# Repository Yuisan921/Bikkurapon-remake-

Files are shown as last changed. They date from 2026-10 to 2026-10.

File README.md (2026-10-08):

# びっくらポン（文化祭リメイク版）

回転寿司でおなじみの「びっくらポン」を、文化祭のミニゲームとして再現するプロジェクトです。

コインを入れる  
→ 画面で抽選演出  
→ 抽選結果を決定  
→ 当たり用 / はずれ用それぞれのホッパーからサーボモーターでカプセルを排出  
→ 結果を画面に表示

という一連の流れを実装しています。

**どちらの結果でも必ずカプセルが1個出ます。**

- 当たり → 当たり用ホッパーから景品カプセルを排出
- はずれ → はずれ用ホッパーから参加賞カプセルを排出

という2ホッパー構成です。

---

# クイックスタート（まずはこれだけ）

## PC側について

このプロジェクトの `.exe` は、一般的な単体アプリとは少し仕組みが異なります。

**パソコンの中で小さなWebサーバーを起動し、その画面をブラウザで表示する方式です。**

ブラウザだけでは、USB接続されたArduinoやコインセンサー、サーボモーターと直接通信できないため、必ず `.exe` を起動した状態で使用します。

逆に言えば、`.exe` が起動していれば、

- ゲーム演出
- 抽選
- 在庫管理
- Arduinoとの通信
- 管理画面

などはすべて自動的に動作します。

## 起動手順

1. `BikkurapoSetup.exe` をインストールする  
   入手方法は後述の「インストーラーを使う」を参照してください。

2. スタートメニューまたはデスクトップの「びっくらポン」を起動する

3. 裏側でサーバーが起動し、自動で次の2つのウィンドウが開きます。

   - **演出画面**
   - **管理画面**

4. 普段のテストでは通常のウィンドウ表示になります。

   文化祭当日に外部モニターへフルスクリーン表示したい場合は、`config/settings.json` の `kiosk_mode` を `true` にしてください。

5. 演出画面右下にある「コインを投入（テスト用）」ボタンを押すと、Arduinoを接続していなくても抽選演出から結果表示まで確認できます。

6. Arduino UNOまたはUNO互換ボードをUSBでノートPCに接続すると、実際のコインセンサーからゲームを開始できるようになります。

   通常はシリアルポートを自動検出します。

   うまく認識されない場合は、`config/settings.json` の `serial_port` に、

   ```json
   "serial_port": "COM3"
``

のようにCOMポートを手動指定してください。

7.  景品、確率、在庫などを変更する場合は `config/prizes.json` を編集します。

## 困ったとき

次の順番で確認すると原因を切り分けやすくなります。

1.  演出画面右下のテストボタンでソフト単体が動くか
2.  `/admin` で在庫が正常に表示されるか
3.  ArduinoがWindowsでCOMポートとして認識されているか
4.  Arduino IDEのシリアルモニターでコイン投入が検知されているか
5.  サーボがArduino単体で正常に動くか

----------

# 全体構成（役割分担）

本体は主に次の2つの機器で構成されています。

## ノートPC

抽選ロジックと画面表示を担当します。

主な役割は次の通りです。

-   抽選処理
-   景品在庫管理
-   演出画面表示
-   管理画面表示
-   ArduinoとのUSBシリアル通信
-   排出予約
-   排出完了確認
-   データ保存

PC側からGPIOなどを直接操作することはありません。

## Arduino UNO / UNO互換ボード

ハードウェア制御を担当します。

主な役割は次の通りです。

-   コインセンサー入力
-   コイン投入検知
-   当たり用サーボ制御
-   はずれ用サーボ制御
-   ノートPCとのUSBシリアル通信
-   カプセル排出完了通知

文化祭本番では、

**Arduino UNO / UNO互換ボード + USB接続**

を標準構成として使用します。

----------

# 使用できるマイコン

このプロジェクトでは複数の接続方法を用意しています。

接続方法

マイコン

ファームウェア

用途

USB（推奨）

Arduino UNO / UNO互換

`firmware/arduino_uno_usb_serial/`

文化祭本番向け。学校にあるUNOを使用可能

USB

Seeed XIAO ESP32-C3

`firmware/xiao_esp32c3_usb_serial/`

小型化したい場合

Wi-Fi

Seeed XIAO ESP32-C3

`firmware/xiao_esp32c3_wifi_http/`

PCとマイコンを離して設置したい場合

文化祭ではWi-Fi環境に左右されず、USBケーブルのみで通信できるArduino UNO版を推奨します。

画面表示に必要なJavaScriptライブラリなどもアプリに同梱しているため、USB版はインターネット接続なしでも動作します。

----------

# 通信の流れ（USB版）

Arduino UNO版とXIAO USB版では、PCとの通信方式を共通化します。

## 1. コイン投入

Arduinoがコインセンサーの投入を検知します。

ArduinoからPCへ、

```
COIN:<番号>
```

を送信します。

例：

```
COIN:1
```

----------

## 2. PC側で抽選

PC側で景品を抽選します。

この時点では、まだ在庫は確定して減らしません。

排出対象がある場合、PCからArduinoへ、

```
DISPENSE:<coinId>:<reservationId>:<hopper>
```

を送信します。

例：

```
DISPENSE:1:abc123:A
```

`hopper` は、

-   `A` → 当たり用ホッパー
-   `B` → はずれ用ホッパー

を表します。

----------

## 3. Arduinoがカプセルを排出

Arduinoは指定されたホッパーのサーボモーターを動かします。

実際にカプセルを排出します。

----------

## 4. 排出完了通知

サーボ動作が完了したら、ArduinoからPCへ、

```
DONE:<reservationId>
```

を返します。

例：

```
DONE:abc123
```

----------

## 5. 在庫確定

PCは `DONE` を受信して初めて在庫を1個減らします。

その後、ゲーム画面へ抽選結果を通知します。

この方式により、

-   USBケーブルが途中で抜けた
-   Arduinoが応答しなかった
-   サーボ排出処理が開始できなかった
-   通信がタイムアウトした

といった場合に、実際には景品が出ていないのに在庫だけ減る事故を防ぎます。

失敗した予約はキャンセルされます。

----------

# Wi-Fi版について

XIAO ESP32-C3を使用する場合はWi-Fi版も利用できます。

Wi-Fi版でも考え方はUSB版と同じです。

カプセル排出後に完了ACKをPCへ送信してから、在庫を確定します。

詳細は、

```
firmware/xiao_esp32c3_wifi_http/xiao_esp32c3_wifi_http.ino
```

のコメントを参照してください。

----------

# カプセル排出機構（CAD）

`cad/capsule_dispenser.scad` に、縦置き中空ドラム式のパラメトリックモデルがあります。

OpenSCADで編集できます。

完成したドラム外観：

![中空ドラムローター外観](cad/capsule_dispenser_drum.png)

前面板を外した内部確認表示：

![中空ドラムローター内部](cad/capsule_dispenser_cutaway.png)

NEMA17用の中央穴と31mm角固定穴：

![ステッピングモーター取付穴](cad/capsule_dispenser_stepper_mount.png)

## 基本構造

画像で検討した円筒をタイヤのように縦置きし、中央のステッピングモーターの水平軸で回転させます。

中空ドラムの外周には180度対向の窓が2個あり、内部は中央仕切りと左右ガイドで1カプセル幅の上下2室に分かれています。

1.  上側のポケットへカプセルが1個入る
2.  ローターを180度回転させる
3.  カプセルが下側へ移動する
4.  排出口からカプセルが落ちる
5.  同時に反対側の空ポケットが上へ移動する
6.  次のカプセルが装填される

という構造です。

ローター回転中はケースの円形内壁がドラム窓を塞ぐため、後続のカプセルが一緒に落ちにくい構造になっています。

ドラムは印刷時の大きなブリッジを避けるため、前面・外周・内部仕切りが一体の `rotor_body` と、後面支持軸付きの `rotor_lid` に分かれています。

当たり用・はずれ用で同じ排出機構を2セット使用します。

## カプセルサイズ

既定値は、一般的な大型カプセルを想定した、

```
capsule_diameter = 65mm
```

です。

実際に使用するカプセルをノギスなどで測定し、必要に応じて変更してください。

例えば、

-   45mm
-   48mm
-   50mm
-   65mm

などに対応できます。

## STL出力

OpenSCADでファイルを開き、冒頭の `PART` を切り替えます。

主なパーツは、

```
"rotor_body"
"rotor_lid"
"housing"
"front_plate"
"rear_plate"
"hopper_adapter"
"outlet_adapter"
```

です。

それぞれ個別にSTLへ出力します。

```
"assembly"
"assembly_cutaway"
```

は組み立て確認用です。`assembly_cutaway` では前面を外し、内部仕切りとカプセル位置を確認できます。

STL出力用ではありません。

`ROTOR_PREVIEW_ANGLE` を、

```
0
```

または、

```
180
```

へ変更すると、ローターの2つの停止位置を確認できます。

## 3Dプリンタサイズ

65mmカプセル設定の場合、ドラムは外径146mm、ケース・前後プレート外形は約156×156mmです。

一般的な、

```
160mm × 160mm
```

の造形範囲へ収まる設計です。ただし、スカートやブリムを付けると160mmを超える場合があるため、スライサー上でも最終確認してください。

## 組み立て

1セットにつき、

-   ローター本体（`rotor_body`）
-   ローター後ろ蓋（`rotor_lid`）
-   ケース
-   フロントプレート
-   リアプレート
-   ホッパーアダプター
-   排出口アダプター

を印刷します。

ローター本体と後ろ蓋はM3低頭ねじ4本で固定します。後ろ蓋には、ねじ頭がケースへ擦らないよう座ぐりがあります。

前後プレートとケースはM4通しボルト4本で固定します。

前面プレート中央には、初期値としてNEMA17用の22.5mm中央穴と31mm角のM3固定穴4個があります。

ローター前面には5.4mmの軸穴と、5mmシャフト用フランジハブを固定する4穴があります。ハブ穴ピッチは製品差があるため、`rotor_hub_*` パラメータを実物へ合わせてください。

ローター後面の軸は `rear_plate` で支持します。

モーターの寸法がNEMA17と異なる場合は、

```
stepper_*
rotor_hub_*
```

系パラメータを実物に合わせて調整してください。

----------

# ステッピングモーターの動作方式

現在の180度ローター構造では、

```
0度
↓
180度
↓
0度
↓
180度
...
```

のように、排出するたびに2つの停止位置を交互に使用する方式が適しています。

排出後に毎回元の位置へ戻さないことで、ローターの1回転分の移動を減らし、排出時間を短縮できます。

ステッピングモーターでは、使用するモーターの1回転ステップ数とマイクロステップ設定から半回転分のパルス数を決めます。原点ずれを確実に防ぐ場合は、別途ホームセンサーの追加を推奨します。

**注意：現在のマイコンファームウェアはサーボ制御のままです。CADの中央ステッピングモーター化に合わせて、STEP/DIRドライバー制御へ変更する必要があります。**

----------

# ホッパー

背の高いカプセル貯留部分は3Dプリントしません。

代わりに、

-   透明アクリルパイプ
-   PET素材の筒
-   透明容器
-   自作ホッパー

などを `hopper_adapter` へ接続します。

65mmカプセルの既定設定では、通路内径は約68.5mmです。

カプセルが単列で流れるようにしてください。

途中で2個が横並びになる構造にすると、詰まりやすくなります。

また、入口直前へ大量のカプセル重量が集中するとローターへ強い力が掛かり、噛み込みが起きる可能性があります。

必要に応じて傾斜板などを設け、ローターへ直接大きな荷重が掛からない構造にしてください。

----------

# ステッピングモーター

CADの初期値は、中央取付の、

**5mm軸NEMA17ステッピングモーター**

へ合わせています。必要トルクはカプセル重量、ホッパー荷重、ドラムの摩擦によって変わるため、実機で余裕を確認してください。

必要数は、

```
2個
```

です。

-   当たり用 ×1
-   はずれ用 ×1

----------

# ステッピングモータードライバーと電源について

ステッピングモーターはArduinoやXIAOの端子へ直接接続できません。モーターごとにA4988やTMC2209などのSTEP/DIR対応ドライバーと、モーター仕様に合う外部電源が必要です。

**モーター電源をマイコンの5V端子から供給しないでください。**

基本構成は、

-   マイコンからドライバーへSTEP/DIR信号
-   外部電源からドライバーへモーター電源
-   マイコンとドライバーのGNDを共通化
-   ドライバーの電流制限を使用モーターへ合わせて調整

です。

使用するドライバーと電源電圧がまだ確定していないため、STEP/DIRのピン番号と配線図はファームウェア変更時に確定します。README後半のサーボ配線・サーボ用ファームウェア説明は現行実装の記録であり、ステッピングモーター版へ更新が必要です。

----------

# リポジトリの構成

```
Bikkurapon-remake-/
│
├─ run.py
│
├─ app/
│  ├─ server.py
│  ├─ lottery.py
│  ├─ serial_bridge.py
│  ├─ paths.py
│  ├─ browser_launcher.py
│  └─ config_setup.py
│
├─ config/
│  ├─ prizes.json
│  └─ settings.json
│
├─ data/
│  └─ stock.json
│
├─ firmware/
│  ├─ arduino_uno_usb_serial/
│  │  └─ arduino_uno_usb_serial.ino
│  │
│  ├─ xiao_esp32c3_usb_serial/
│  │  └─ xiao_esp32c3_usb_serial.ino
│  │
│  └─ xiao_esp32c3_wifi_http/
│     └─ xiao_esp32c3_wifi_http.ino
│
├─ cad/
│  └─ capsule_dispenser.scad
│
├─ templates/
│
├─ static/
│
├─ scripts/
│
├─ installer/
│
├─ tests/
│
├─ bikkurapon.spec
├─ requirements.txt
├─ requirements-dev.txt
├─ requirements-build.txt
└─ README.md
```

## 主なファイル

### `run.py`

アプリの起動エントリーポイントです。

### `app/server.py`

Flask + Socket.IOによるサーバー本体です。

ノートPC上で動作します。

### `app/lottery.py`

-   確率抽選
-   景品選択
-   在庫管理
-   排出予約

などを担当します。

### `app/serial_bridge.py`

Arduino UNOまたはXIAO ESP32-C3とのUSBシリアル通信を担当します。

-   コイン投入受信
-   排出命令送信
-   DONE応答受信
-   再接続処理

などを行います。

### `app/paths.py`

通常のPython実行とPyInstallerによる `.exe` 実行時のパス解決を切り替えます。

### `app/browser_launcher.py`

起動時に、

-   演出画面
-   管理画面

を自動的にブラウザで開きます。

### `bikkurapon.spec`

PyInstallerで `.exe` を作成するための設定です。

### `installer/bikkurapon.iss`

Inno SetupでWindowsインストーラーを作るための設定です。

### `.github/workflows/build-windows.yml`

GitHub Actions上のWindows環境で、

-   テスト
-   `.exe` 作成
-   インストーラー作成

を自動実行します。

### `config/prizes.json`

次の内容を設定します。

-   景品
-   当選確率
-   初期在庫
-   使用するホッパー

### `config/settings.json`

次のような設定を行います。

-   HTTPポート
-   USBシリアルポート
-   ブラウザ自動起動
-   キオスクモード
-   外部アクセス許可
-   デバッグボタン表示

### `templates/`, `static/`

-   演出画面 `/`
-   在庫管理画面 `/admin`

に使用するHTML、CSS、JavaScriptなどです。

### `data/stock.json`

現在の在庫数を保存します。

実行時に自動生成されます。

Git管理対象外です。

### `firmware/arduino_uno_usb_serial/`

Arduino UNO / UNO互換ボード用のUSBシリアル版ファームウェアです。

**文化祭本番での推奨構成です。**

### `firmware/xiao_esp32c3_usb_serial/`

Seeed XIAO ESP32-C3用USBシリアル版です。

### `firmware/xiao_esp32c3_wifi_http/`

Seeed XIAO ESP32-C3用Wi-Fi版です。

### `cad/capsule_dispenser.scad`

カプセル排出機構のパラメトリックCADです。

### `scripts/`

開発用の起動スクリプトや `.exe` ビルドスクリプトなどが入っています。

----------

# 必要なハードウェア

## 推奨構成

-   WindowsノートPC
-   Arduino UNO または UNO互換ボード
-   USB Type-Bケーブル
-   コインセンサー
-   高トルク180度サーボ ×2
-   サーボ用外部5〜6V電源
-   ブレッドボードまたは配線基板
-   ジャンパーワイヤ
-   カプセル排出機構 ×2
-   カプセル
-   外部モニター（任意）

## 推奨サーボ

MG996R相当の、

-   金属ギア
-   高トルク
-   180度動作

のサーボを推奨します。

----------

# Arduino UNO配線

## 基本配線

部品

Arduino UNO

コインセンサー信号

D2

当たり用ホッパー サーボ信号

D9

はずれ用ホッパー サーボ信号

D10

GND

GND

D0とD1はUSBシリアル通信で使用されるため、通常は使いません。

## コインセンサー

コインセンサーは、

**投入時にLOWになる構成**

を想定しています。

Arduino側では、

```
pinMode(COIN_SENSOR_PIN, INPUT_PULLUP);
```

を使用します。

そのためテスト時には普通のスイッチでも代用できます。

```
Arduino D2
   │
   └── スイッチ ── GND
```

スイッチを押すとLOWになり、コイン投入として扱われます。

----------

# セットアップ

# ノートPC側 その1：インストーラーを使う（推奨）

Windowsのユーザー名に、

-   日本語
-   ひらがな
-   カタカナ
-   その他の非ASCII文字

などが含まれている場合、Python仮想環境やバッチファイル周辺で文字コード関連の問題が起きることがあります。

そのため、このプロジェクトではGitHub Actions上のWindows環境で `.exe` とインストーラーを自動生成できるようにしています。

## 入手方法

1.  GitHubリポジトリの `Actions` タブを開く
    
2.  `build-windows.yml` の最新ビルドを開く
    
3.  Artifacts欄から、
    
    ```
    BikkurapoSetup
    ```
    
    をダウンロードする
    
4.  ZIPを展開する
    
5.  中にある、
    
    ```
    BikkurapoSetup.exe
    ```
    
    を実行する

ビルドがまだ存在しない場合や最新化したい場合は、GitHub Actionsから、

```
Run workflow
```

を実行してください。

----------

# インストール・実行

`BikkurapoSetup.exe` を起動してインストールすると、

-   スタートメニュー
-   デスクトップ

に「びっくらポン」のショートカットが作成されます。

ショートカットをダブルクリックすると、

1.  Webサーバー起動
2.  Arduino接続待機
3.  演出画面起動
4.  管理画面起動

まで自動的に行われます。

バッチファイルを手動で実行する必要はありません。

----------

# 設定ファイルの保存場所

設定フォルダの場所は、実行ファイルの場所へ書き込み可能かどうかによって変わります。

例えば、

```
C:\Program Files\
```

のような一般ユーザーが書き込めない場所へインストールした場合は、

```
%LOCALAPPDATA%\Bikkurapon\config\
```

へ設定ファイルが作成されます。

在庫データも、

```
%LOCALAPPDATA%\Bikkurapon\data\
```

側へ保存されます。

現在使用している設定フォルダは、起動時のコンソールにも、

```
設定フォルダ: ...
```

として表示されます。

----------

# アンインストール

Inno Setup製インストーラーにはアンインストーラーが自動的に付属します。

削除する場合は、次のどちらかを使用できます。

## 方法1

スタートメニューの「びっくらポン」フォルダ内にある、

```
Uninstall びっくらポン
```

を実行します。

## 方法2

Windowsの、

```
設定
→ アプリ
→ インストールされているアプリ
```

から「びっくらポン」を探してアンインストールします。

新しいバージョンへ更新する場合は、基本的に上書きインストール可能です。

必ずアンインストールする必要はありません。

----------

# ノートPC側 その2：.exeを自分でビルドする

インストーラーを使わず、自分で `.exe` を作成することもできます。

Windowsの場合、

```
scripts\build_exe.bat
```

を実行します。

成功すると、

```
dist\bikkurapon.exe
```

が生成されます。

ダブルクリックすると、

-   サーバー
-   演出画面
-   管理画面

が起動します。

初回起動時には必要に応じて、

```
config\
data\
```

が自動作成されます。

以降、景品や確率を変更するだけなら `.exe` を作り直す必要はありません。

## 注意

PyInstallerで生成される実行ファイルは、

**ビルドしたOS向けの実行ファイルです。**

Windowsでビルドした場合はWindows用になります。

----------

# ノートPC側 その3：Pythonで直接動かす（開発用）

Python環境から直接実行する場合は、仮想環境を作成します。

Mac / Linux：

```
python3 -m venv venv
source venv/bin/activate
pip install -r requirements.txt
python run.py
```

Windows：

```
python -m venv venv
venv\Scripts\activate
pip install -r requirements.txt
python run.py
```

Arduinoが接続されていなくてもアプリ自体は起動できます。

バックグラウンドでUSBシリアル接続を待ち続けます。

後からArduinoを接続して、

```
USBシリアルに再接続しました
```

と表示されれば接続成功です。

----------

# シリアルポートを手動設定する

自動検出できない場合は、

```
config/settings.json
```

の `serial_port` を指定します。

Windowsの例：

```
"serial_port": "COM3"
```

Linux系の例：

```
"serial_port": "/dev/ttyACM0"
```

ポート番号は環境によって変わります。

Arduino IDEの、

```
ツール
→ ポート
```

から確認できます。

----------

# 演出画面

アプリ起動後、

```
http://localhost:5000/
```

で演出画面へアクセスできます。

通常は自動的に開くため、手入力する必要はありません。

----------

# 管理画面

管理画面は、

```
http://localhost:5000/admin
```

です。

こちらも通常は自動的に開きます。

----------

# 演出画面・管理画面の自動起動

サーバーを起動すると、

```
app/browser_launcher.py
```

が、

-   演出画面
-   管理画面

を自動的に別ウィンドウで起動します。

通常はタイトルバー付きウィンドウとして開きます。

1台のモニターでテストするときは自由に移動できます。

----------

# ブラウザ自動起動を無効にする

`config/settings.json` の、

```
"auto_open_browser": false
```

を指定すると、自動起動を無効化できます。

その場合は手動で、

```
http://localhost:5000/
```

と、

```
http://localhost:5000/admin
```

を開いてください。

----------

# キオスクモード

文化祭本番で演出画面を外部モニターへフルスクリーン表示する場合は、

```
"kiosk_mode": true
```

を設定します。

演出画面がタイトルバーなしのフルスクリーン表示になります。

来場者が誤ってブラウザ操作したり、別ページへ移動したりすることを防ぎやすくなります。

普段の開発中は、

```
"kiosk_mode": false
```

を推奨します。

----------

# 外部モニター位置

演出画面を外部モニターの決まった位置へ表示したい場合は、

```
"kiosk_window_position": "1920,0"
```

のように指定できます。

数値はWindowsのディスプレイ配置によって異なります。

分からない場合は、

```
"kiosk_window_position": null
```

のままにして、手動でウィンドウを移動してください。

ChromeまたはChromiumが見つからない場合は、既定ブラウザで演出画面のみ開く場合があります。

その場合、管理画面は手動で `/admin` を開いてください。

----------

# 開発用起動スクリプト

開発用として、

```
scripts/start_bikkurapon.bat
```

および、

```
scripts/start_bikkurapon.sh
```

があります。

これらは環境構築とサーバー起動を補助するスクリプトです。

ブラウザ自体はサーバー側から起動します。

----------

# Arduino UNO側セットアップ

## 必要なもの

-   Arduino IDE
-   Arduino UNO / UNO互換ボード
-   USB Type-Bケーブル

Arduino UNOの場合、通常は追加ボードパッケージは必要ありません。

## ボード設定

Arduino IDEで、

```
ツール
→ ボード
→ Arduino AVR Boards
→ Arduino Uno
```

を選択します。

## ポート

ArduinoをUSB接続して、

```
ツール
→ ポート
```

からArduinoのCOMポートを選びます。

----------

# Arduino UNOファームウェア

次のファイルをArduino IDEで開きます。

```
firmware/arduino_uno_usb_serial/arduino_uno_usb_serial.ino
```

Arduino UNOへ書き込んでください。

----------

# Arduino UNOで使用するライブラリ

サーボ制御には、

```
#include <Servo.h>
```

を使用します。

Arduino標準のServoライブラリを使用するため、通常は別途ライブラリを追加する必要はありません。

----------

# Arduino UNOのピン

標準設定では、

```
const int COIN_SENSOR_PIN = 2;
const int SERVO_A_PIN = 9;
const int SERVO_B_PIN = 10;
```

とします。

つまり、

機能

ピン

コインセンサー

D2

当たりサーボ

D9

はずれサーボ

D10

です。

----------

# シリアル通信速度

PCとのUSBシリアル通信は、

```
115200 baud
```

を使用します。

Arduino IDEのシリアルモニターを開く場合も115200に設定してください。

----------

# Arduino単体でコイン検知を確認する

PCアプリを起動する前に、Arduino IDEのシリアルモニターで確認できます。

コインセンサーを反応させると、

```
COIN:1
```

次の投入では、

```
COIN:2
```

のように連番が表示されます。

----------

# XIAO ESP32-C3 USB版

Arduino UNOを使用しない場合は、既存のXIAO ESP32-C3 USB版も利用できます。

ファームウェア：

```
firmware/xiao_esp32c3_usb_serial/xiao_esp32c3_usb_serial.ino
```

Arduino IDEで、

```
XIAO_ESP32C3
```

を選択します。

さらに、

```
Tools
→ USB CDC On Boot
→ Enabled
```

へ設定してください。

USBシリアル通信に必要です。

## 必要ライブラリ

```
ESP32Servo
```

を使用します。

----------

# XIAO ESP32-C3 Wi-Fi版

Wi-Fi通信を使用する場合は、

```
firmware/xiao_esp32c3_wifi_http/
```

を使用します。

ファームウェア内の、

```
WIFI_SSID
WIFI_PASSWORD
SERVER_URL
DEVICE_TOKEN
```

を設定してください。

PC側の `config/settings.json` では、

```
"host": "0.0.0.0",
"allow_remote_insert_coin": true
```

などを設定する必要があります。

`device_token` は16文字以上の推測されにくい文字列を推奨します。

PC側とESP32側で同じ値を設定してください。

----------

# インターネットなしのルーター / APでWi-Fi版を使用する

Wi-Fi版はインターネット接続自体は必要ありません。

ノートPCとESP32が同じLAN内にいれば通信できます。

## 手順

1.  ルーターのDHCPを有効にする
    
2.  ノートPCとESP32を同じSSIDへ接続する
    
3.  ゲストWi-FiやAP分離機能は使用しない
    
4.  Windowsで、
    
    ```
    ipconfig
    ```
    
    を実行する
    
5.  ノートPCのIPv4アドレスを確認する
    
6.  ESP32の `SERVER_URL` を、
    
    ```
    http://<PCのIP>:5000/api/insert_coin
    ```
    
    に設定する
    
7.  PCの `settings.json` で、
    
    ```
    "host": "0.0.0.0",
    "allow_remote_insert_coin": true
    ```
    
    を有効にする
    
8.  Windowsファイアウォールの確認が表示されたら、プライベートネットワークを許可する

Socket.IOなど、画面表示に必要なライブラリも、

```
static/vendor/
```

から読み込むため、WAN側のインターネット接続は不要です。

USB版ではこの設定は必要ありません。

----------

# 景品・確率のカスタマイズ

景品設定は、

```
config/prizes.json
```

を編集します。

既定では、

-   当たり
-   はずれ

の2種類です。

例：

```
{
  "id": "atari",
  "name": "当たり",
  "probability": 0.2,
  "stock": 30,
  "hopper": "a"
}
```

## probability

当選確率です。

例：

```
"probability": 0.2
```

なら20%です。

各景品の確率合計が、

```
1.0
```

になるように設定してください。

----------

# stock

初期在庫数です。

例：

```
"stock": 30
```

なら30個です。

```
"stock": null
```

にすると在庫無制限として扱います。

----------

# hopper

使用する排出ホッパーです。

```
"hopper": "a"
```

→ 当たり用

```
"hopper": "b"
```

→ はずれ用

```
"hopper": null
```

→ カプセルを排出しない

という意味です。

----------

# 在庫切れになった景品

在庫が0になった景品は自動的に抽選対象から除外されます。

残っている景品だけを使用して再抽選されます。

----------

# 全景品の在庫がなくなった場合

全景品の在庫がなくなると、抽選はエラー扱いになります。

この場合、

-   カプセルを排出しない
-   在庫を減らさない
-   マイコンへ排出なしを通知
-   演出画面を在庫切れ表示へ変更

します。

演出画面には、

```
巫女さんを呼んでください
```

と表示されます。

管理画面から在庫を補充すると、自動的に通常の待機画面へ戻ります。

在庫切れ中にコインを投入した来場者への対応は、スタッフ側でメダル返却などを行う想定です。

`stock: null` の景品を1つ用意しておけば、全在庫切れ状態にはなりません。

----------

# 初期在庫を変更した場合

`config/prizes.json` の初期在庫を変更しても、既に、

```
data/stock.json
```

が存在する場合は現在在庫が優先されます。

初期在庫から作り直したい場合は、

```
data/stock.json
```

を削除してからアプリを再起動してください。

----------

# インストーラーを入れ直しても景品設定が変わらない場合

インストーラーは、既にユーザー設定ファイルが存在する場合、それをできるだけ維持します。

そのため、古いバージョンの、

```
config/prizes.json
```

が残っていると、新しい `.exe` に入れ替えても設定が変わらない場合があります。

設定フォルダは通常、

```
%LOCALAPPDATA%\Bikkurapon\config\
```

です。

必要に応じて、

```
prizes.json
```

を確認してください。

古い既定形式を検出した場合は、

```
prizes.json.bak
```

としてバックアップを作成してから新しい形式へ差し替える処理があります。

完全に初期化したい場合は、アプリ終了後に既存の `prizes.json` を削除してから再起動してください。

----------

# 在庫管理画面

管理画面は、

```
http://localhost:5000/admin
```

です。

ゲーム起動時に自動的に開きます。

管理画面では、

-   景品名
-   現在在庫
-   在庫変更

などを確認できます。

カプセルを補充した場合は数値を変更して更新してください。

ゲーム画面側へ即座に反映されます。

----------

# 管理画面の外部アクセス

既定では、管理画面や在庫変更操作は、

**ゲームを動かしているPC自身からのみ使用可能**

です。

文化祭会場のWi-Fiへ接続した来場者から勝手に在庫を書き換えられることを防ぐためです。

スマートフォンなど別端末から管理する場合は、

```
"host": "0.0.0.0",
"allow_remote_admin": true
```

へ変更します。

その後、

```
http://<ノートPCのIP>:5000/admin
```

へアクセスしてください。

## 注意

この設定を有効にすると、同じネットワークへ接続している他の端末からアクセスできる可能性があります。

使用後は、

```
"allow_remote_admin": false
```

へ戻すことを推奨します。

----------

# テスト

開発用依存パッケージをインストールします。

```
pip install -r requirements-dev.txt
```

その後、

```
pytest
```

を実行します。

主に次の処理をテストしています。

-   抽選ロジック
-   景品在庫
-   在庫切れ
-   排出予約
-   排出ACK
-   DONE応答
-   タイムアウト
-   アクセストークン
-   USBシリアル再接続
-   保存先
-   旧データ移行

GitHub ActionsによるWindowsビルド前にもテストを自動実行します。

----------

# 本番前チェック

文化祭本番前に、最低限次の項目を確認してください。

-   Arduinoが正常に認識される
-   コイン投入を検知できる
-   連続投入しても二重検知しない
-   当たりサーボが正常に動く
-   はずれサーボが正常に動く
-   当たり用カプセルが1個だけ出る
-   はずれ用カプセルが1個だけ出る
-   カプセルが途中で詰まらない
-   USBケーブルを抜いた場合に在庫が減らない
-   Arduinoを再接続すると復旧する
-   全在庫切れ画面が正常に出る
-   在庫補充後に待機画面へ戻る
-   管理画面から在庫変更できる
-   外部モニターへ正しく表示される
-   キオスクモードが正常に動く
-   デバッグ用ボタンが非表示になっている

----------

# 運用上の注意

## 現金について

実際の現金を直接投入させ、抽選によって景品を渡す形式は、運用方法によって法律上の問題が生じる可能性があります。

文化祭では、

-   文化祭用チケット
-   事前購入メダル
-   専用コイン

などを使用する運用を推奨します。

----------

# デバッグボタン

本番当日は、

```
config/settings.json
```

の、

```
"show_debug_button": false
```

を設定してください。

演出画面右下のテスト用コイン投入ボタンが非表示になります。

なお、これは画面上のボタンを非表示にする設定です。

PC自身からのAPI処理がすべて無効になるわけではありません。

----------

# USBケーブル

文化祭本番では、ArduinoとPCを接続するUSBケーブルが抜けないよう固定してください。

USB Type-Bは比較的抜けにくいですが、

-   ケーブルクランプ
-   結束バンド
-   テープ

などでケーブルへ直接力が掛からないようにしておくと安全です。

----------

# Arduino D0 / D1について

Arduino UNOの、

```
D0
D1
```

はUSBシリアル通信で使用します。

そのため、

-   コインセンサー
-   サーボ
-   その他の外部機器

には基本的に使用しないでください。

本プロジェクトでは、

```
D2
D9
D10
```

を使用します。

----------

# サーボ電源

サーボモーターはArduino UNOの5V端子から直接給電せず、外部5〜6V電源を使用してください。

また、

**Arduinoとサーボ電源のGNDは必ず共通にしてください。**

----------

# 演出のカスタマイズ

演出画面の、

-   色
-   アニメーション
-   背景
-   当たり演出
-   はずれ演出

などは、

```
static/css/style.css
```

などを編集することで変更できます。

代表的なクラスとして、

```
.state-atari
.state-hazure
```

などがあります。

----------

# 本番用ルーターについて

USB版を使用する場合、ゲーム本体にルーターは必要ありません。

Wi-Fi版やスマートフォンから管理画面を使用する場合のみLAN環境が必要です。

Wi-Fi版を使う場合もインターネット回線自体は不要です。

ノートPCのIPアドレスが変わるとESP32から接続できなくなるため、ルーター側でDHCP予約を設定してIPアドレスを固定すると安定します。

----------

# 推奨する本番構成

最終的な推奨構成は次の通りです。

```
                   ┌─────────────────┐
                   │    外部モニター   │
                   │   ゲーム演出表示   │
                   └────────▲────────┘
                            │ HDMI等
                            │
┌───────────────────────────┴────────┐
│              ノートPC               │
│                                    │
│ Flask + Socket.IO                  │
│ 抽選                               │
│ 在庫管理                           │
│ 演出画面                           │
│ 管理画面                           │
│                                    │
└────────────────┬───────────────────┘
                 │
                 │ USB Type-B
                 ▼
        ┌─────────────────┐
        │   Arduino UNO    │
        │                  │
        │ D2  コイン入力   │
        │ D9  当たりServo  │
        │ D10 はずれServo  │
        └───┬──────┬──────┘
            │      │
            │      │
       ┌────▼─┐  ┌─▼────┐
       │当たり│  │はずれ │
       │Servo │  │Servo  │
       └──────┘  └───────┘
            ▲        ▲
            │        │
            └────┬───┘
                 │
          外部5〜6V電源
```

コイン投入から景品排出まで、

```
コイン投入
↓
Arduinoが検知
↓
PCへCOIN送信
↓
PCで抽選
↓
ArduinoへDISPENSE送信
↓
サーボ動作
↓
カプセル排出
↓
ArduinoからDONE
↓
在庫確定
↓
結果表示
```

という流れになります。

----------

# 最後に

このプロジェクトは、文化祭当日にできるだけ安定して動作することを重視しています。

特に、

-   PCとマイコンの役割を分離する
-   USB接続を標準にする
-   サーボ電源を別系統にする
-   排出完了後に在庫を確定する
-   在庫切れを自動検知する
-   管理画面を別に用意する

ことで、トラブルが起きても原因を切り分けやすい構成にしています。

本番前には必ず実際のカプセル、サーボ、ホッパーを使用して繰り返し動作テストを行ってください。

```

これなら**元READMEの内容を途中で落とさず、UNO移行まで含めたREADMEとしてかなり完成形に近い**。

特に元のREADMEには、在庫切れ時の「巫女さんを呼んでください」、インストーラー上書き時の設定保持、管理画面の外部アクセス制限、GitHub Actionsのテストなども書かれていたので、その辺も削らず残してある。:chatgpt-content-reference{index="1"}

ただし1つだけ、**このREADMEをGitへ入れる前にUNO版 `.ino` も作る必要がある**。READMEだけ先に更新すると `firmware/arduino_uno_usb_serial/` が存在しない状態になるから、次はそこを完成させればGit全体が噛み合うよ。🔧
```

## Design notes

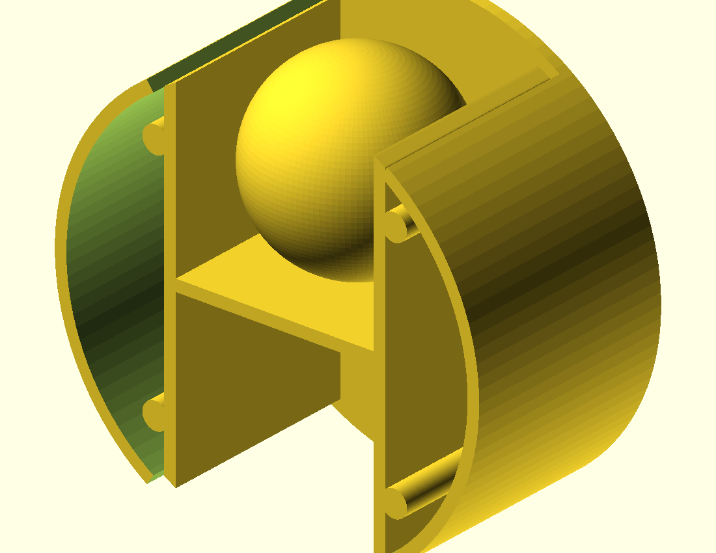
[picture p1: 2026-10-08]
cad/capsule_dispenser_cutaway.png

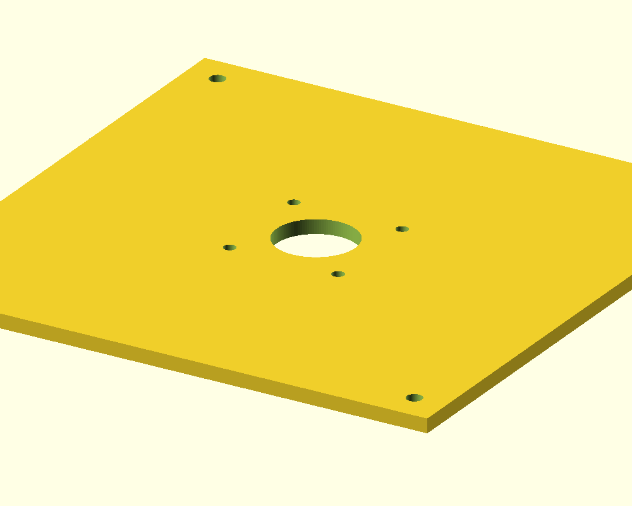
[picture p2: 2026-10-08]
cad/capsule_dispenser_stepper_mount.png

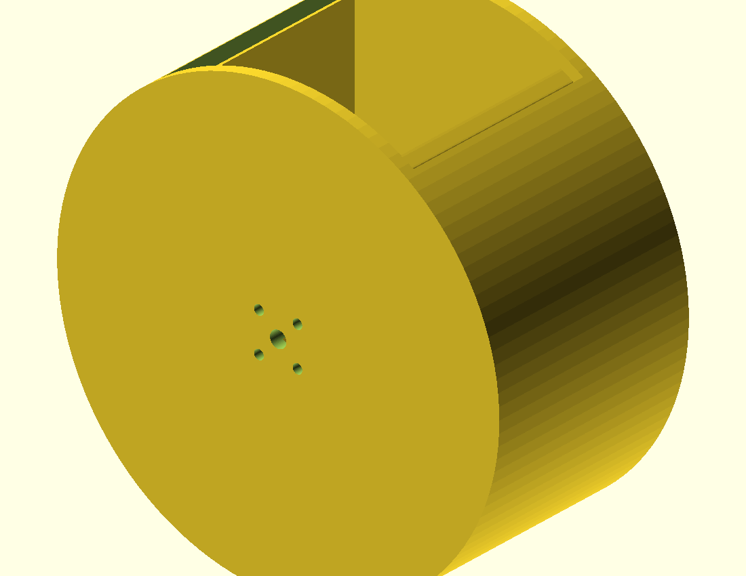
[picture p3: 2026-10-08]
cad/capsule_dispenser_drum.png

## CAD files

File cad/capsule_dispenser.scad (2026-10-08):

/* ==========================================================================
 * びっくらポン 中空ドラム式180度カプセルディスペンサー
 * ==========================================================================
 *
 * 画像で検討した円筒ドラムをタイヤのように縦置きし、水平なモーター軸で
 * 0度と180度へ交互に回す機構。ドラム外周には180度対向の窓があり、
 * 上の窓でカプセルを1個受け、半回転後に下の窓から排出する。
 *
 * ドラム内部は単なる空洞ではなく、中央仕切りと左右ガイドによって
 * 1カプセル幅の上下2室に分かれている。これにより複数個の入り込みと
 * ドラム内部での横逃げを抑える。回転中はhousingの円形内壁が窓を塞ぐ。
 *
 * 印刷時の大きなブリッジを避けるため、回転体は次の2部品に分割する。
 *   rotor_body : 前面板、外周、内部仕切りを一体印刷
 *   rotor_lid  : 後ろ蓋、後面支持軸を一体印刷
 * M3ねじ4本で後ろ蓋をrotor_bodyへ固定する。
 *
 * 座標系（assembly表示時）:
 *   X = 左右、Y = 前後（回転軸）、Z = 上下
 * ========================================================================== */

// ---- 出力する部品 ----
PART = "assembly_cutaway";
// "rotor_body" / "rotor_lid" / "housing" /
// "front_plate" / "rear_plate" /
// "hopper_adapter" / "outlet_adapter" /
// "rotor" / "rotor_cutaway" / "assembly" / "assembly_cutaway"

// assembly表示時のローター位置。0と180が停止位置。
ROTOR_PREVIEW_ANGLE = 0;
SHOW_PREVIEW_CAPSULE = true;
SHOW_STEPPER_PREVIEW = true;

// ---- カプセル ----
// 必ず使用するカプセルを実測して変更すること。
capsule_diameter = 65;
pocket_clearance = 3.0;
throat_clearance = 3.5;

// ---- 中空ドラムローター ----
pocket_width = capsule_diameter + pocket_clearance;
pocket_depth = capsule_diameter + pocket_clearance;

drum_shell = 4;
drum_front_thickness = 4;
drum_lid_thickness = 4;
// 65mmカプセル時でも最大部品を160mm未満へ収めるため、上室の
// 高さをカプセル1個分＋最小限の逃げに詰める。
drum_inner_radius = capsule_diameter + 4;
drum_outer_radius = drum_inner_radius + drum_shell;
drum_depth = pocket_depth + drum_front_thickness + drum_lid_thickness;

divider_thickness = 4;
guide_wall_thickness = 4;

// 窓はカプセル径より少し広い扇形。角度を増やすほど入りやすいが、
// housingに塞がれる距離が短くなるため、必要以上に広げない。
window_angle = 2 * asin(pocket_width / (2 * drum_inner_radius)) + 10;

// 後ろ蓋固定用M3。ねじ頭はrear側から締める。
rotor_lid_screw_diameter = 3.4;
rotor_lid_screw_head_diameter = 6.4;
rotor_lid_screw_head_depth = 2.2;
rotor_body_pilot_diameter = 2.7;
rotor_screw_boss_diameter = 9;
rotor_screw_radius = drum_inner_radius - 11;
rotor_body_pilot_depth = 14;

// 後面支持軸
rear_pivot_diameter = 10;
rear_pivot_clearance = 0.6;
rear_pivot_length = 10;

// ---- 中央ステッピングモーター（初期値: NEMA17） ----
// 使用するモーターとシャフトハブを実測して調整すること。
stepper_body_size = 42.3;
stepper_body_depth = 40;
stepper_mount_spacing = 31;
stepper_mount_hole_diameter = 3.4;
stepper_pilot_diameter = 22.5;
stepper_shaft_diameter = 5;
stepper_shaft_clearance = 0.4;
stepper_shaft_length = 24;
stepper_shaft_engagement_depth = 14;

// ドラム前面へ市販の5mmシャフト用フランジハブを固定する4穴。
// ハブ製品によって穴ピッチが異なるため、必ず実物に合わせること。
rotor_hub_hole_circle = 18;
rotor_hub_mount_hole_diameter = 3.2;

// ---- ケース／前後プレート ----
radial_clearance = 0.8;
axial_clearance = 0.7;
housing_wall = 5;
housing_depth = drum_depth + axial_clearance * 2;
housing_width = (drum_outer_radius + housing_wall) * 2;
housing_height = housing_width;
throat_diameter = capsule_diameter + throat_clearance;

front_plate_thickness = 4;
rear_plate_thickness = 4;
case_bolt_diameter = 4.4;
case_bolt_edge = 9;

// ---- ホッパー／排出口アダプター ----
adapter_flange_width = 90;
adapter_flange_depth = housing_depth;
adapter_flange_thickness = 4;
adapter_wall = 3.5;
hopper_neck_height = 32;
outlet_neck_height = 20;
adapter_bolt_diameter = 3.4;
adapter_bolt_x = 34;
adapter_bolt_y = housing_depth/2 - 7;

$fn = 120;

// ==========================================================================
// 共通ヘルパー
// ==========================================================================

module cylinder_y(d, h) {
    rotate([90, 0, 0]) cylinder(d=d, h=h, center=true);
}

// XZ平面上の扇形をY方向へ押し出す。
module sector_y(radius, center_angle, sweep_angle, depth, steps=24) {
    start_angle = center_angle - sweep_angle/2;
    rotate([90, 0, 0])
        linear_extrude(height=depth, center=true)
            polygon(points=concat(
                [[0, 0]],
                [for (i = [0:steps])
                    [radius*cos(start_angle + sweep_angle*i/steps),
                     radius*sin(start_angle + sweep_angle*i/steps)]]
            ));
}

module case_bolt_pattern(depth) {
    for (x = [-housing_width/2 + case_bolt_edge,
              housing_width/2 - case_bolt_edge])
        for (z = [-housing_height/2 + case_bolt_edge,
                  housing_height/2 - case_bolt_edge])
            translate([x, 0, z]) cylinder_y(case_bolt_diameter, depth);
}

module adapter_bolt_pattern(height) {
    for (x = [-adapter_bolt_x, adapter_bolt_x])
        for (y = [-adapter_bolt_y, adapter_bolt_y])
            translate([x, y, -1])
                cylinder(d=adapter_bolt_diameter, h=height + 2);
}

module rotor_lid_screw_pattern(depth, diameter, y_center) {
    for (angle = [45, 135, 225, 315])
        translate([
            rotor_screw_radius*cos(angle),
            y_center,
            rotor_screw_radius*sin(angle)
        ])
            cylinder_y(diameter, depth);
}

module stepper_mount_pattern(depth, diameter, y_center=0) {
    for (x = [-stepper_mount_spacing/2, stepper_mount_spacing/2])
        for (z = [-stepper_mount_spacing/2, stepper_mount_spacing/2])
            translate([x, y_center, z])
                cylinder_y(diameter, depth);
}

module rotor_hub_mount_pattern(depth, diameter, y_center) {
    for (angle = [45, 135, 225, 315])
        translate([
            rotor_hub_hole_circle/2*cos(angle),
            y_center,
            rotor_hub_hole_circle/2*sin(angle)
        ])
            cylinder_y(diameter, depth);
}

// ==========================================================================
// 中空ドラムローター本体
// ==========================================================================

module drum_side_shell(body_depth) {
    difference() {
        difference() {
            cylinder_y(drum_outer_radius*2, body_depth);
            cylinder_y(drum_inner_radius*2, body_depth + 2);
        }

        // 上下180度対向のカプセル窓。
        for (angle = [90, 270])
            sector_y(
                drum_outer_radius + 3,
                angle,
                window_angle,
                body_depth + 4
            );
    }
}

module internal_divider_and_guides() {
    // 前面板へ少し食い込ませ、面接触だけの非一体形状になるのを防ぐ。
    feature_depth = pocket_depth + 0.8;
    feature_center_y = -0.4;

    // 中央の床。半回転すると反対側ポケットの天井になる。
    intersection() {
        translate([0, feature_center_y, 0])
            cylinder_y(drum_inner_radius*2 + 0.4, feature_depth);
        translate([0, feature_center_y, 0])
            cube([
                pocket_width + guide_wall_thickness*2,
                feature_depth,
                divider_thickness
            ], center=true);
    }

    // カプセルが左右へ逃げないための2枚のガイド。
    for (x = [
        -(pocket_width + guide_wall_thickness)/2,
         (pocket_width + guide_wall_thickness)/2
        ])
        intersection() {
            translate([0, feature_center_y, 0])
                cylinder_y(drum_inner_radius*2 + 0.4, feature_depth);
            translate([x, feature_center_y, 0])
                cube([
                    guide_wall_thickness,
                    feature_depth,
                    drum_inner_radius*2 + 1
                ], center=true);
        }
}

module rotor_body_raw(include_front_face=true) {
    body_depth = drum_depth - drum_lid_thickness;
    body_center_y = -drum_lid_thickness/2;
    front_y = -drum_depth/2 + drum_front_thickness/2;

    union() {
        translate([0, body_center_y, 0])
            drum_side_shell(body_depth);

        if (include_front_face)
            translate([0, front_y, 0])
                cylinder_y(drum_outer_radius*2, drum_front_thickness);

        internal_divider_and_guides();

        // 後ろ蓋ねじ用ボス。カプセル通路の外側へ配置。
        rotor_lid_screw_pattern(
            pocket_depth + 0.8,
            rotor_screw_boss_diameter,
            -0.4
        );
    }
}

module rotor_body_mechanical(include_front_face=true) {
    body_rear_y = drum_depth/2 - drum_lid_thickness;
    front_surface_y = -drum_depth/2;
    front_face_y = front_surface_y + drum_front_thickness/2;

    difference() {
        rotor_body_raw(include_front_face);

        if (include_front_face) {
            // NEMA17の5mm軸がドラム中心へ入る穴。
            translate([
                0,
                front_surface_y + stepper_shaft_engagement_depth/2,
                0
            ])
                cylinder_y(
                    stepper_shaft_diameter + stepper_shaft_clearance,
                    stepper_shaft_engagement_depth + 1
                );

            // 市販のシャフト用フランジハブをドラム前面へ固定する穴。
            rotor_hub_mount_pattern(
                drum_front_thickness + 2,
                rotor_hub_mount_hole_diameter,
                front_face_y
            );
        }

        // 本体側はM3タッピング用の止まり穴。
        rotor_lid_screw_pattern(
            rotor_body_pilot_depth + 1,
            rotor_body_pilot_diameter,
            body_rear_y - rotor_body_pilot_depth/2 + 0.5
        );
    }
}
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

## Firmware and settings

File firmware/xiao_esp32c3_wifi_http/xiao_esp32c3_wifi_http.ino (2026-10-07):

/*
 * びっくらポン ハードウェア担当ファームウェア(Seeed XIAO ESP32-C3用)
 *
 * 当たり用・はずれ用、それぞれ専用のホッパー(サーボ)を1個ずつ、
 * 計2個のサーボをこの1枚のESP32で制御する。
 *
 * コインセンサーの投入を検知したら、ノートPCで動いているFlaskサーバーの
 * /api/insert_coin にPOSTする。レスポンスのJSONの "hopper" フィールドが
 * "a" なら当たり用ホッパー、"b" ならはずれ用ホッパーのサーボを動かして
 * カプセルを排出する。null ならどちらも動かさない。排出後は
 * /api/dispense_ack へ完了応答を送り、それを受けて在庫と当選画面が確定する。
 * APIには共有トークンを付け、同じWiFiにいる他端末からの不正な抽選を防ぐ。
 * サーボの角度自体はこのファームウェアの固定値(ホッパーごとの現物合わせ)
 * で、サーバー側は「どちらのホッパーか」だけを指定する。
 *
 * 必要なライブラリ(Arduino IDEのライブラリマネージャからインストール):
 *   - ESP32Servo (by Kevin Harrington)
 *   - ArduinoJson 7.x (by Benoit Blanchon)
 * ボード設定: "XIAO_ESP32C3" を選択(esp32 by Espressif Systems のボードパッケージ内)
 *
 * 配線例:
 *   - コインセンサー信号線 -> D0(内部プルアップ、投入でLOWになる想定)
 *   - 当たり用ホッパーのサーボ信号線 -> D1
 *   - はずれ用ホッパーのサーボ信号線 -> D2
 */

#include <WiFi.h>
#include <HTTPClient.h>
#include <ArduinoJson.h>
#include <ESP32Servo.h>

// ここを会場のWiFiとノートPCのIPアドレスに書き換える
const char *WIFI_SSID = "your-wifi-ssid";
const char *WIFI_PASSWORD = "your-wifi-password";
const char *SERVER_URL = "http://192.168.1.100:5000/api/insert_coin";
// config/settings.json の device_token と同じ16文字以上の値にする
const char *DEVICE_TOKEN = "change-this-device-token";

const int COIN_SENSOR_PIN = D0;

const int SERVO_A_PIN = D1;   // 当たり用ホッパー
const int SERVO_B_PIN = D2;   // はずれ用ホッパー

// 2ポケットローターは0度と180度のどちらでも装填／排出できる。
// 角度は個体差が大きいので、実機で組み立てたあとに調整すること。
const int SERVO_A_POSITION_0   = 0;
const int SERVO_A_POSITION_180 = 180;
const int SERVO_B_POSITION_0   = 0;
const int SERVO_B_POSITION_180 = 180;

const unsigned long SERVO_SETTLE_MS = 1000;
const unsigned long DEBOUNCE_MS = 300;

Servo servoA;
Servo servoB;
bool servoAAt180 = false;
bool servoBAt180 = false;
unsigned long lastTriggerMs = 0;
<<<<<<< HEAD
bool coinWasLow = false;
=======
bool coinArmed = true;
>>>>>>> 251ce8c766819690cefd0f56fca9b64794677e31

void setup() {
  Serial.begin(115200);
  pinMode(COIN_SENSOR_PIN, INPUT_PULLUP);

  servoA.attach(SERVO_A_PIN);
  servoA.write(SERVO_A_POSITION_0);
  servoB.attach(SERVO_B_PIN);
  servoB.write(SERVO_B_POSITION_0);

  connectToWifi();
}

void loop() {
  if (WiFi.status() != WL_CONNECTED) {
    connectToWifi();
  }

<<<<<<< HEAD
  bool coinIsLow = digitalRead(COIN_SENSOR_PIN) == LOW;
  if (coinIsLow && !coinWasLow) {
=======
  bool coinLow = digitalRead(COIN_SENSOR_PIN) == LOW;
  if (coinLow && coinArmed) {
>>>>>>> 251ce8c766819690cefd0f56fca9b64794677e31
    unsigned long now = millis();
    if (now - lastTriggerMs > DEBOUNCE_MS) {
      lastTriggerMs = now;
      coinArmed = false;
      handleCoinInserted();
    }
  } else if (!coinLow) {
    coinArmed = true;
  }
  coinWasLow = coinIsLow;

  delay(20);
}

void connectToWifi() {
  Serial.print("WiFiに接続中: ");
  Serial.println(WIFI_SSID);
  WiFi.begin(WIFI_SSID, WIFI_PASSWORD);

  unsigned long startMs = millis();
  while (WiFi.status() != WL_CONNECTED && millis() - startMs < 15000) {
    delay(300);
    Serial.print(".");
  }

  if (WiFi.status() == WL_CONNECTED) {
    Serial.println();
    Serial.print("接続完了: ");
    Serial.println(WiFi.localIP());
  } else {
    Serial.println();
    Serial.println("WiFi接続に失敗しました。次のループで再試行します。");
  }
}

void handleCoinInserted() {
  Serial.println("コイン投入を検知。サーバーに通知します。");

  if (WiFi.status() != WL_CONNECTED) {
    Serial.println("WiFi未接続のため送信できません。");
    return;
  }

  HTTPClient http;
  http.begin(SERVER_URL);
  http.addHeader("Content-Type", "application/json");
  http.addHeader("X-Bikkurapon-Token", DEVICE_TOKEN);
  int statusCode = http.POST("{}");

  if (statusCode == 200) {
    String payload = http.getString();
    Serial.println("抽選結果: " + payload);
    JsonDocument doc;
    DeserializationError err = deserializeJson(doc, payload);
    if (err) {
      Serial.print("JSON解析に失敗しました: ");
      Serial.println(err.c_str());
      http.end();
      return;
    }

    if (doc["hopper"].isNull() || doc["reservation_id"].isNull()) {
      Serial.println("どちらのホッパーも動かしません。");
      http.end();
      return;
    }

    String reservationId = doc["reservation_id"].as<String>();
    String hopper = doc["hopper"].as<String>();
    // 次のACK送信用HTTP接続を開く前に、抽選リクエストの接続を閉じる。
    http.end();
    bool success = dispenseIfWon(hopper.c_str());
    sendDispenseAck(reservationId, success);
    return;
  } else {
    Serial.printf("サーバー通信エラー: %d\n", statusCode);
  }

  http.end();
}

bool dispenseIfWon(const char *hopper) {
  if (strcmp(hopper, "a") == 0) {
    Serial.println("当たり: ホッパーAからカプセルを排出します。");
<<<<<<< HEAD
    advanceRotor(
      servoA, servoAAt180, SERVO_A_POSITION_0, SERVO_A_POSITION_180
    );
  } else if (strcmp(hopper, "b") == 0) {
    Serial.println("はずれ景品: ホッパーBからカプセルを排出します。");
    advanceRotor(
      servoB, servoBAt180, SERVO_B_POSITION_0, SERVO_B_POSITION_180
    );
=======
    dispenseFrom(servoA, SERVO_A_REST_ANGLE, SERVO_A_DISPENSE_ANGLE);
    return true;
  } else if (strcmp(hopper, "b") == 0) {
    Serial.println("はずれ景品: ホッパーBからカプセルを排出します。");
    dispenseFrom(servoB, SERVO_B_REST_ANGLE, SERVO_B_DISPENSE_ANGLE);
    return true;
>>>>>>> 251ce8c766819690cefd0f56fca9b64794677e31
  } else {
    Serial.printf("[WARN] 想定外のhopper値: %s\n", hopper);
    return false;
  }
}

<<<<<<< HEAD
void advanceRotor(Servo &servo, bool &at180, int position0, int position180) {
  at180 = !at180;
  servo.write(at180 ? position180 : position0);
  delay(SERVO_SETTLE_MS);
=======
void sendDispenseAck(const String &reservationId, bool success) {
  String ackUrl = SERVER_URL;
  ackUrl.replace("/api/insert_coin", "/api/dispense_ack");

  JsonDocument ackDoc;
  ackDoc["reservation_id"] = reservationId;
  ackDoc["success"] = success;
  String body;
  serializeJson(ackDoc, body);

  // 応答だけ失われた場合にも届くよう最大3回送る。サーバーが既に処理済みの
  // 場合は409を返すので、それも到達済みとして終了する。
  for (int attempt = 0; attempt < 3; attempt++) {
    HTTPClient ackHttp;
    ackHttp.begin(ackUrl);
    ackHttp.addHeader("Content-Type", "application/json");
    ackHttp.addHeader("X-Bikkurapon-Token", DEVICE_TOKEN);
    int statusCode = ackHttp.POST(body);
    ackHttp.end();
    if (statusCode == 200 || statusCode == 409) {
      return;
    }
    delay(250);
  }
  Serial.println("[WARN] 排出完了ACKをサーバーへ送れませんでした。");
}

void dispenseFrom(Servo &servo, int restAngle, int dispenseAngle) {
  servo.write(dispenseAngle);
  delay(SERVO_HOLD_MS);
  servo.write(restAngle);
>>>>>>> 251ce8c766819690cefd0f56fca9b64794677e31
}

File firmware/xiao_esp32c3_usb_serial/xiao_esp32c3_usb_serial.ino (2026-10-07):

/*
 * びっくらポン ハードウェア担当ファームウェア(Seeed XIAO ESP32-C3 / USB接続版)
 *
 * XIAO ESP32-C3をUSBケーブルでノートPCに直結して使う版。WiFiは使わない。
 * 当たり用・はずれ用、それぞれ専用のホッパー(サーボ)を1個ずつ、
 * 計2個のサーボをこの1枚のESP32で制御する。
 *
 * コインセンサーの投入を検知したら、USBシリアル経由でノートPCに
 * "COIN:<連番>" を送る。ノートPC側が予約番号付きのDISPENSE命令を返し、
 * サーボ動作後に "DONE:<予約番号>" を返して初めて在庫と当選表示を確定する。
 * タイムアウトやUSB切断時は予約が取り消され、在庫だけ減ることを防ぐ。
 *
 * Arduino IDE設定:
 *   - ボード: "XIAO_ESP32C3" を選択(esp32 by Espressif Systems のボードパッケージ内)
 *   - Tools > USB CDC On Boot: "Enabled" にすること
 *     (これをしないとUSB経由のシリアル通信が正しく使えません)
 * 必要なライブラリ:
 *   - ESP32Servo (by Kevin Harrington)
 *
 * 配線例:
 *   - コインセンサー信号線 -> D0(内部プルアップ、投入でLOWになる想定)
 *   - 当たり用ホッパーのサーボ信号線 -> D1
 *   - はずれ用ホッパーのサーボ信号線 -> D2
 */

#include <ESP32Servo.h>

const int COIN_SENSOR_PIN = D0;

const int SERVO_A_PIN = D1;   // 当たり用ホッパー
const int SERVO_B_PIN = D2;   // はずれ用ホッパー

// 2ポケットローターは0度と180度のどちらでも装填／排出できる。
// 角度は個体差が大きいので、実機で組み立てたあとに調整すること。
const int SERVO_A_POSITION_0   = 0;
const int SERVO_A_POSITION_180 = 180;
const int SERVO_B_POSITION_0   = 0;
const int SERVO_B_POSITION_180 = 180;

const unsigned long SERVO_SETTLE_MS = 1000;
const unsigned long DEBOUNCE_MS = 300;
const unsigned long RESPONSE_TIMEOUT_MS = 3000;

Servo servoA;
Servo servoB;
bool servoAAt180 = false;
bool servoBAt180 = false;
unsigned long lastTriggerMs = 0;
<<<<<<< HEAD
bool coinWasLow = false;
=======
unsigned long coinSequence = 0;
bool coinArmed = true;
>>>>>>> 251ce8c766819690cefd0f56fca9b64794677e31

void setup() {
  Serial.begin(115200);
  pinMode(COIN_SENSOR_PIN, INPUT_PULLUP);

  servoA.attach(SERVO_A_PIN);
  servoA.write(SERVO_A_POSITION_0);
  servoB.attach(SERVO_B_PIN);
  servoB.write(SERVO_B_POSITION_0);
}

void loop() {
<<<<<<< HEAD
  bool coinIsLow = digitalRead(COIN_SENSOR_PIN) == LOW;
  if (coinIsLow && !coinWasLow) {
=======
  bool coinLow = digitalRead(COIN_SENSOR_PIN) == LOW;
  if (coinLow && coinArmed) {
>>>>>>> 251ce8c766819690cefd0f56fca9b64794677e31
    unsigned long now = millis();
    if (now - lastTriggerMs > DEBOUNCE_MS) {
      lastTriggerMs = now;
      coinArmed = false;
      handleCoinInserted();
    }
  } else if (!coinLow) {
    // 一度投入を処理したら、信号がHIGHへ戻るまで次の投入を受け付けない。
    coinArmed = true;
  }
  coinWasLow = coinIsLow;
  delay(20);
}

void handleCoinInserted() {
  String coinId = String(++coinSequence);
  Serial.println("COIN:" + coinId);

  String response = waitForResponse(coinId, RESPONSE_TIMEOUT_MS);
  if (response.length() == 0) {
    Serial.println("[WARN] ノートPCからの応答がタイムアウトしました。");
    return;
  }

  dispenseIfWon(response);
}

String waitForResponse(const String &coinId, unsigned long timeoutMs) {
  unsigned long startMs = millis();
  String noneResponse = "NONE:" + coinId;
  String dispensePrefix = "DISPENSE:" + coinId + ":";
  while (millis() - startMs < timeoutMs) {
    if (Serial.available()) {
      String line = Serial.readStringUntil('\n');
      line.trim();
      // 前回タイムアウト後に遅れて届いた命令はcoinIdが違うので捨てる。
      if (line == noneResponse || line.startsWith(dispensePrefix)) {
        return line;
      }
    }
  }
  return "";
}

void dispenseIfWon(const String &response) {
  if (response.startsWith("NONE:")) {
    Serial.println("はずれ扱い: どちらのホッパーも動かしません。");
    return;
  }

  // DISPENSE:<coinId>:<reservationId>:<hopper>
  int firstColon = response.indexOf(':');
  int secondColon = response.indexOf(':', firstColon + 1);
  int thirdColon = response.indexOf(':', secondColon + 1);
  if (firstColon < 0 || secondColon < 0 || thirdColon < 0) {
    Serial.println("[WARN] 想定外の応答: " + response);
    return;
  }
  String reservationId = response.substring(secondColon + 1, thirdColon);
  String hopper = response.substring(thirdColon + 1);
  bool success = false;

  if (hopper == "A") {
    Serial.println("当たり: ホッパーAからカプセルを排出します。");
<<<<<<< HEAD
    advanceRotor(
      servoA, servoAAt180, SERVO_A_POSITION_0, SERVO_A_POSITION_180
    );
    return;
=======
    dispenseFrom(servoA, SERVO_A_REST_ANGLE, SERVO_A_DISPENSE_ANGLE);
    success = true;
>>>>>>> 251ce8c766819690cefd0f56fca9b64794677e31
  }
  else if (hopper == "B") {
    Serial.println("はずれ景品: ホッパーBからカプセルを排出します。");
<<<<<<< HEAD
    advanceRotor(
      servoB, servoBAt180, SERVO_B_POSITION_0, SERVO_B_POSITION_180
    );
    return;
=======
    dispenseFrom(servoB, SERVO_B_REST_ANGLE, SERVO_B_DISPENSE_ANGLE);
    success = true;
  } else {
    Serial.println("[WARN] 想定外のホッパー: " + hopper);
>>>>>>> 251ce8c766819690cefd0f56fca9b64794677e31
  }

  String ack = success ? "DONE:" : "FAILED:";
  ack += reservationId;
  Serial.println(ack);
}

void advanceRotor(Servo &servo, bool &at180, int position0, int position180) {
  at180 = !at180;
  servo.write(at180 ? position180 : position0);
  delay(SERVO_SETTLE_MS);
}

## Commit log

2026-09-06 文化祭向けびっくらポン風カプセルゲームを実装
    コイン投入(GPIO/テストAPI)をトリガーに確率抽選を行い、結果をSocket.IOで
    画面へ通知してサーボモーターでカプセルを排出する一連の流れをFlaskで構築。
    景品ごとの在庫管理と、実機GPIOがない環境向けのモックモードも用意した。
    Claude-Session: https://claude.ai/code/session_01BU8Apwr2szsLDsDYBXL9XF
2026-09-06 実機構成をノートPC + XIAO ESP32-C3に合わせて変更
    サーバー(ノートPC)がGPIOを直接触る設計をやめ、コインセンサー/サーボモーターは
    XIAO ESP32-C3側で直接制御する構成に変更。ESP32はコイン投入を検知すると
    ノートPCの/api/insert_coinにHTTP POSTするだけで、抽選結果(サーボ角度含む)は
    そのレスポンスとして受け取るため、サーバー側からESP32への逆方向通信は不要。
    ESP32用の参考ファームウェア(Arduino)をfirmware/以下に追加した。
    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
2026-09-07 XIAO ESP32-C3ファームウェアをArduinoJson 7系に対応
    Arduino IDEのライブラリマネージャで新規インストールすると最新の
    ArduinoJson 7系が入るため、非推奨のStaticJsonDocumentからJsonDocumentに変更。
    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
2026-09-07 USB接続によるXIAO ESP32-C3連携を追加
    会場WiFiに依存せず安定動作させたいという要望に対応するため、USBシリアル経由の
    コイン投入通知を実装。ESP32が"COIN"を送るとサーバーが抽選し、"DISPENSE:<角度>"
    または"NONE"を1行返すシンプルなテキストプロトコル。ポートは既知のUSB-Serialチップの
    VID/説明文から自動検出し、見つからない場合はsettings.jsonで明示指定できる。
    USB版ファームウェア(firmware/xiao_esp32c3_usb_serial/)を新規追加し、既存のWiFi版は
    firmware/xiao_esp32c3_wifi_http/に整理した。仮想シリアルポート(socat)でPython側の
    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
2026-09-07 演出画面と管理画面を2ウィンドウで同時に開く起動スクリプトを追加
    文化祭当日の起動を簡単にするため、サーバー起動 + 演出画面(外部モニターに
    フルスクリーン) + 管理画面(ノートPC本体に通常ウィンドウ)を1コマンドで
    まとめて開くスクリプトをWindows/Mac/Linux向けに用意した。
    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
2026-09-07 カプセル排出機構のOpenSCADパラメトリックCADを追加
    回転ゲート式(ホッパー+ポケット1個の回転ディスク+ベース)のカプセル
    ディスペンサーをOpenSCADで作成。当たり用・はずれ用(弱景品)で同じ設計を
    2セット印刷する想定。capsule_diameterやサーボ寸法をパラメータとして
    調整できる。
    OpenSCAD 2021.01でレンダリング・STL出力し、admeshで水密性(穴なし・
    退化面なし)を検証済み。当初、排出シュートの壁が排出口の穴とちょうど
    同じ幅で1点接触しており非2-manifold形状になっていたため、シュート幅を
    穴より少し広げて修正し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
    [capsule_dispenser.scad]
2026-09-07 カプセル排出CADを3Dプリンタの造形サイズ制約に対応させて修正
    200x200x170mm級のプリンタでは元のホッパー設計(高さ約166mm)がギリギリ
    すぎたため、カプセルを大量に貯める背の高い部分を3Dプリント対象から外し、
    市販の透明アクリルパイプ/クリアな容器を接着して使う前提の
    throat_adapter(のど+襟のみ、高さ約114mm)に置き換えた。
    また、のど・襟部分が中身の詰まったソリッド形状になっており、カプセルが
    通る空洞が存在しない不具合を発見したため、内部をテーパー付きの空洞として
    正しくくり抜くよう修正。Ope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
    [capsule_dispenser.scad]
2026-09-07 PyInstallerで.exe化できるようにする
    Pythonの環境構築なしで文化祭当日にダブルクリックだけで起動できるよう、
    PyInstallerでの単体実行ファイル化に対応。
    - app/paths.py: 通常実行時とexe化(PyInstaller)時でのパス解決を切り替える
    ヘルパーを追加。exe化時はtemplates/staticをバンドル内(_MEIPASS)から、
    config/dataはexe本体と同じフォルダから読み書きする
    - app/server.py: 初回起動時、exeの隣にconfigフォルダが無ければ同梱の
    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
2026-09-07 Windowsインストーラーとブラウザ自動起動を追加
    日本語(ひらがな等)ユーザー名の環境でbatファイルが正しく動かない問題への
    対応として、以下を実装した。
    - app/browser_launcher.py: サーバー起動時に演出画面(キオスクモード)と
    管理画面を自動でブラウザに開く処理をPython側に実装。これまでbatスクリプト
    が担っていた役割をexe自身が持つことで、bat経由の処理を不要にした
    - installer/bikkurapon.iss: Inno Setup用のWindowsインストーラー設定。
    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
2026-09-07 プラダン等の柔らかい板に取り付けるための補強リングを追加
    キャビネットをレーザーカット不要なプラダン(プラスチック段ボール)で作る
    場合、baseのネジ穴の力を柔らかい板が直接受けると穴がヘタりやすいため、
    base_plateと同じネジ穴パターンを持つ3Dプリント製の補強リング
    (mount_bracket)を追加した。プラダンとbaseの間に挟んで使う。
    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
    [capsule_dispenser.scad]
2026-09-07 ソフトウェアを2ホッパー構成(当たり/はずれ別サーボ)に合わせて全面修正
    これまで会話で「大当たりは無くし、はずれでも弱景品を出す2ホッパー構成」に
    決めていたが、ソフト側(prizes.json・server.py・ファームウェア)が
    旧来の3層・1ホッパー設計(servo_angle: 90/45/null)のまま食い違っていたため、
    全体を2ホッパー構成に合わせて直した。
    - config/prizes.json: 大当たり/当たり/はずれの3層から、当たり/はずれの2層に
    変更。各景品にservo_angleの代わりhopper("a"/"b")を持たせ、どちらの
    結果でも必ずカプセルが出る設計にした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
    [serial_bridge.py, server.py, test_lottery.py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]
2026-09-07 READMEにクイックスタートを追加し、.exeの仕組みを明記
    「.exeと言いつつブラウザベースで動いているのか」「USB接続はブラウザだけで
    繋がるのか」という質問に答える形で、.exeの正体(ローカルWebサーバー)と
    ブラウザとの関係を冒頭で明記した。あわせて、演出画面・管理画面が
    自動で別ウィンドウとして開く挙動を、仮想ディスプレイ(Xvfb+fluxbox)上で
    実際にwmctrlでウィンドウ一覧を確認し、2つの独立したウィンドウ
    (「びっくらポン!」「びっくらポン 管理画面」)が生成されることを検証した。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
2026-09-07 管理画面で確率を編集可能にし、再描画時のフォーカス消失を修正
    - app/lottery.py, app/server.py: 景品の当選確率を管理画面から変更できる
    API(/api/set_probability)を追加。変更はconfig/prizes.jsonにも書き戻され、
    再起動後も保持される。在庫状況に合わせて確率を調整したり、テスト用に
    わざと確率を偏らせたりする用途を想定
    - static/js/admin.js: コイン投入のたびにテーブル全体を作り直していたため、
    入力中でもフォーカスやTabでの移動先が毎回リセットされていた。
    行(input要素)を使い回す実装に変更し、フォーカス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
    [lottery.py, server.py, test_lottery.py]
2026-09-07 演出画面をタイトルバー付きの通常ウィンドウで開くよう変更(既定でキオスクモードをオフに)
    演出画面が常に枠なしのキオスクモードで開いていたため、1台のモニターで
    テストする際にウィンドウをドラッグして動かせず操作しづらいという報告に対応。
    - config/settings.json に kiosk_mode(既定 false)を追加。true の時だけ
    演出画面がタイトルバーなしのフルスクリーンになる(文化祭当日の外部
    モニター表示用)
    - app/browser_launcher.py: 演出画面・管理画面それぞれに専用の Chrome
    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
2026-09-07 READMEにアンインストール方法を追記
    Inno Setup製インストーラーには標準でアンインストーラーが自動生成される
    (installer/bikkurapon.iss に Uninstallable=no の指定はなく、デフォルトで
    有効)。学校のPCで古いビルドを消してから最新版を入れ直したいという
    要望があったが、既に付属しているスタートメニューの「Uninstall びっくらポン」
    または Windows の「アプリ」設定から削除できるため、その手順をREADMEに
    明記した。
    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
2026-09-07 古いconfig/が残っていて新しいexeに入れ替えても景品構成が変わらない不具合を修正
    原因: config/ フォルダは「実行ファイルの隣にまだ無い時だけ」同梱の既定値を
    コピーする仕様だった。config/ はインストーラーの管理対象外(アプリが実行時に
    作るファイル)なので、アンインストールしても、新しいバージョンを上書き
    インストールしても消えずに残り続ける。そのため、大当たりがあった頃の古い
    prizes.json が一度でも作られると、以降どれだけ新しいexeに入れ替えても
    その内容がずっと使われ続けていた。
    修正: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
    [config_setup.py, server.py, test_config_setup.py]
2026-09-08 カプセル排出機構: 「のど」の隙間を詰めて低在庫時の信頼性を上げる
    当たり/はずれの決定はソフト側(app/lottery.py)の抽選で先に決まっているため、
    この機構に物理的なランダム性(実物のガチャガチャのように山盛りから偶然
    1個掴む動き)は不要で、「指定された1個を残り1個でも確実に落とす」信頼性
    だけが求められる。そこで、カプセルが1列に並ぶ「のど」の隙間を
    capsule_diameter+3mm(片側1.5mm)からcapsule_diameter+2mm(片側1mm)に
    詰め、残り1個になった時にカプセルが斜めになってポケットとうまく
    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
    [capsule_dispenser.scad]
2026-09-30 Cadデータ変更
    [capsule_dispenser.scad]
2026-10-06 在庫切れ時に巫女さん呼び出し画面を出し、本番運用向けに堅牢化
    - 全景品の在庫が尽きたら OutOfStock を投げ、在庫・ホッパーはそのままに
    演出画面へ「巫女さんを呼んでください」画面を通知(補充で自動復帰)
    - 管理系API・/admin・/api/insert_coin を既定でローカルのみに制限
    (host / allow_remote_admin / allow_remote_insert_coin で許可)
    - exeの隣に書き込めない場合は %LOCALAPPDATA%\Bikkurapon に退避
    - stock.json / prizes.json を一時ファイル+os.replaceで原子的に書き込み
    - シリアル受信スレッドが処理中の例外で死なないようにし、USB切断時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
    [lottery.py, paths.py, serial_bridge.py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]
2026-10-06 Fix offline hardware flow and stock consistency
    [config_setup.py, lottery.py, paths.py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]
2026-10-07 何かしら
    何かしら
2026-10-08 Scad変更
    Scad変更
    [capsule_dispenser.scad]
2026-10-11 Cadデータ追加
2026-10-16 Bikkuraponをデスクトップアプリとして再設計
